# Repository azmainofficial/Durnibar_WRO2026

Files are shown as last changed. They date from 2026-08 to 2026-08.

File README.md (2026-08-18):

<div align="center">
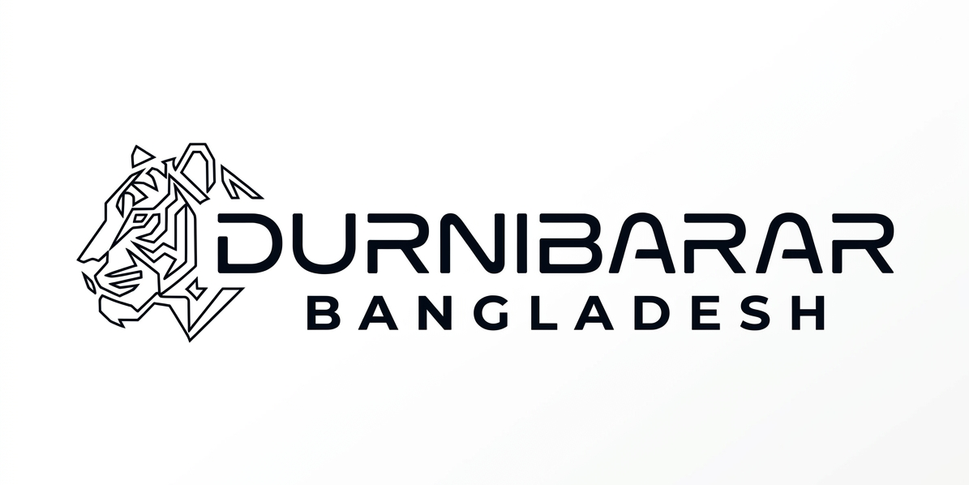
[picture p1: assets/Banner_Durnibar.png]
Team Durnibar Banner
  
  <h1>🏎️ Team Durnibar — WRO 2026 Future Engineers</h1>
  <p><strong>Official Repository & Technical Documentation for World Robot Olympiad 2026 (Self-Driving Cars)</strong></p>
  <p>Representing <strong>Bangladesh 🇧🇩</strong></p>

  
  
  
  
  
</div>

---

## 📌 Table of Contents

- [1. Team Introduction](#1-team-introduction)
- [2. Mission & WRO 2026 Rules Overview](#2-mission--wro-2026-rules-overview)
- [3. Vehicle System Architecture](#3-vehicle-system-architecture)
- [4. Repository Folder Hierarchy](#4-repository-folder-hierarchy)
- [5. Mechanical & Kinematic Design](#5-mechanical--kinematic-design)
- [6. Power & Sensor Management (Wiring & Pinout)](#6-power--sensor-management-wiring--pinout)
- [7. Software Modules, Telemetry & Algorithm Strategy](#7-software-modules-telemetry--algorithm-strategy)
- [8. Hardware Components & Bill of Materials](#8-hardware-components--bill-of-materials)
- [9. Build, Calibration & Run Instructions](#9-build-calibration--run-instructions)
- [10. Autonomous Demonstration Videos](#10-autonomous-demonstration-videos)
- [11. Judging Criteria & Documentation Index](#11-judging-criteria--documentation-index)

---

## 1. Team Introduction

**Team Durnibar** is a collegiate robotics team from Bangladesh competing in the **Future Engineers** category at the **World Robot Olympiad (WRO) 2026**.

<table align="center">
  <tr>
    <td align="center" width="33%">
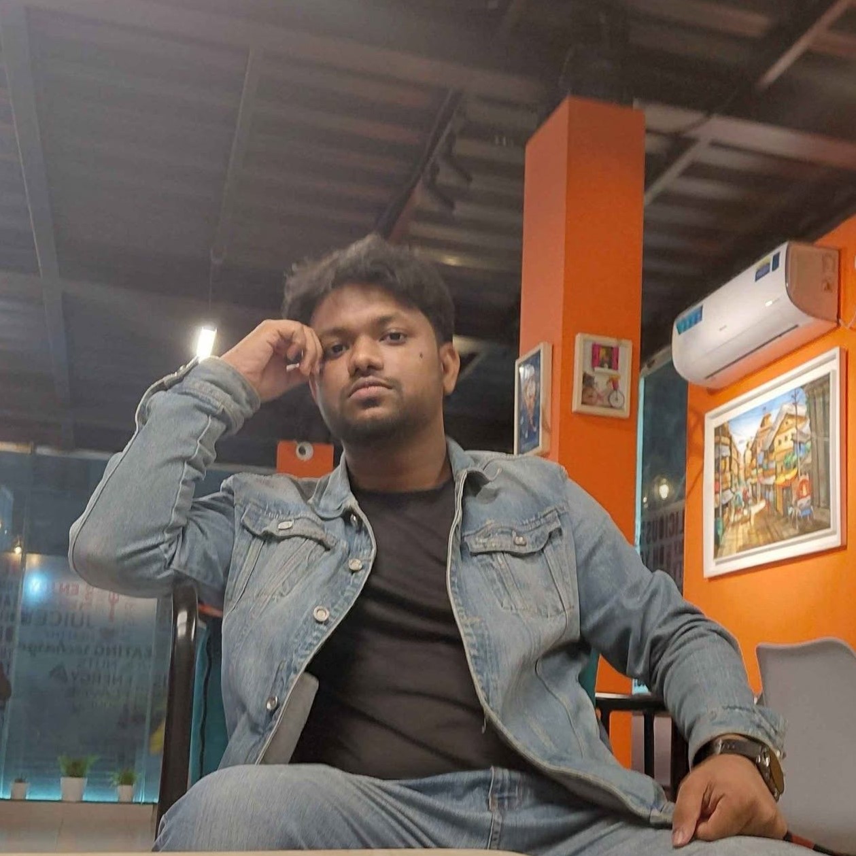
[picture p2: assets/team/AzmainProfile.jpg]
      <br><br>
      <strong>Azmain Shak Rubayed</strong><br>
      <sub>Team Lead / CAD & Vision Systems</sub><br>
      <sub>Fusion 360, ROS 2, OpenCV, Python</sub><br>
      <a href="mailto:rubayed_41220200226@nub.ac.bd">✉️ Email</a>
    </td>
    <td align="center" width="33%">
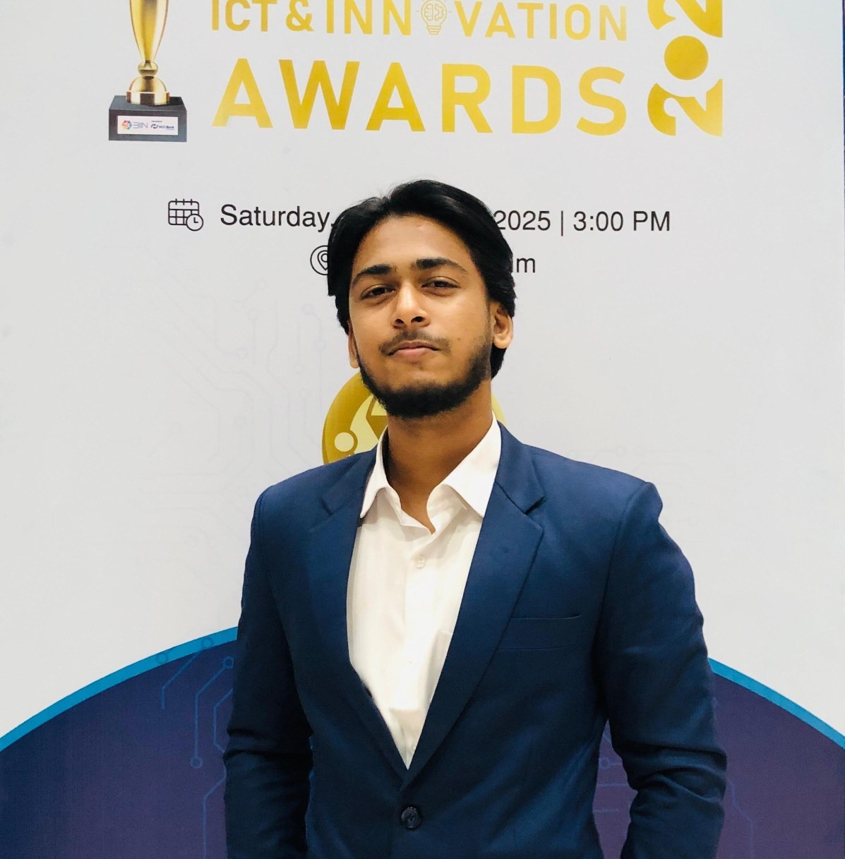
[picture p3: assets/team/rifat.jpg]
      <br><br>
      <strong>Rifat Ahmmed</strong><br>
      <sub>Embedded Software & Control</sub><br>
      <sub>Independent University Bangladesh</sub><br>
      <a href="mailto:ra7260352@email.com">✉️ Email</a>
    </td>
    <td align="center" width="33%">
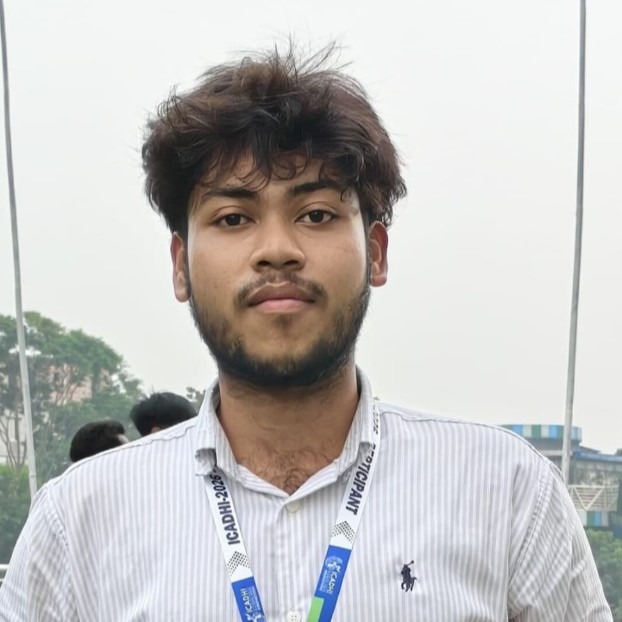
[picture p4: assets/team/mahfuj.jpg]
      <br><br>
      <strong>Mahfuj Rohoman</strong><br>
      <sub>Electronics & Hardware Integration</sub><br>
      <sub>Independent University, Bangladesh</sub><br>
      <a href="mailto:member3@email.com">✉️ Email</a>
    </td>
  </tr>
</table>

---

## 2. Mission & WRO 2026 Rules Overview

The **WRO 2026 Future Engineers Self-Driving Cars** category challenges teams to engineer an autonomous 4-wheeled robotic vehicle capable of high-speed navigation, obstacle traffic sign obedience, and autonomous parallel parking on a randomly configured racetrack.

b3b44990-8981-4bee-be3b-6bd4b68e230d

### WRO 2026 Competition Challenges

#### 1. Open Challenge
- Complete **3 autonomous laps** on a track with randomly configured inner walls.
- Navigate corridors with variable widths of **600 mm or 1000 mm**.
- After completing the third lap, the robot must **autonomously stop completely within the designated finish area (with custom 15cm forward wall-avoidance adjustment)**.

#### 2. Obstacle Challenge
- Complete **3 autonomous laps** while correctly following traffic signs:
  - **Red Pillar → Keep Right**
  - **Green Pillar → Keep Left**
- Perform **autonomous parallel parking** inside a designated **20 cm-wide parking area**.



### Key Technical Rule Compliance Checklist
- **Rule 11.1 & 11.2**: Max dimensions $300 \text{ mm (L)} \times 200 \text{ mm (W)} \times 300 \text{ mm (H)}$, max weight $1.5 \text{ kg}$.
- **Rule 11.3 & 11.13**: 4-wheeled vehicle with **one single driving axle** connected via gearbox and **one steering actuator**. Differential drive (skid steering) and independent side motors are strictly prohibited.
- **Rule 9.10 & 9.11**: Vehicle power activated by **exactly one main switch**; program execution triggered by **exactly one start button**.
- **Rule 11.10**: Strictly 100% autonomous operation — no RF, Bluetooth, Wi-Fi, or remote communication during competition attempts.

---

## 3. Vehicle System Architecture

**Durnibar 2.0 ("Sulg")** uses a decoupled two-tier architecture balancing ROS 2 high-level navigation with real-time microcontroller actuator response:

```
┌─────────────────────────────────────────────────────────────────────────┐
│              HIGH-LEVEL COMPUTATION — RASPBERRY PI 5 (8GB)              │
│   • ROS 2 Humble/Jazzy Operating Framework                              │
│   • Slamtec RPLIDAR C1 (360° DTOF LaserScan Navigation & Wall Tracking) │
│   • Fifine K420 2K Webcam (108° FOV OpenCV Traffic Sign Color Detection)│
│   • High-Level ROS 2 Finite State Machine (FSM) Decision Node           │
└────────────────────────────────────┬────────────────────────────────────┘
                                     │ High-Speed UART (115200 Baud)
┌────────────────────────────────────▼────────────────────────────────────┐
│                    LOW-LEVEL CONTROLLER — ESP32 MCU                     │
│   • TB6612FNG H-Bridge Motor Driver (PWMA=13, AIN1=12, AIN2=14, STBY=27)  │
│   • Quadrature Wheel Encoder ISR (A=34, B=35) & 1D Kalman Speed Filter  │
│   • MPU6050 6-DOF IMU + QMC5883L Compass + SSD1306 OLED Display (I2C)   │
│   • Closed-Loop Steering Servo PWM (GPIO 25) & Status LEDs / Buzzer     │
└─────────────────────────────────────────────────────────────────────────┘
```

---

## 4. Repository Folder Hierarchy

```
Sulg/ (Workspace Root)
├── Sulg.ino                 # ESP32 Main Sketch Setup & Loop
├── config.h                 # ESP32 pin definitions & parameters
├── globals.h                # Global state external declarations
├── imu.cpp / imu.h          # MPU6050 & QMC5883L IMU sensor fusion
├── motor.cpp / motor.h      # TB6612 Motor driver control functions
├── encoder.cpp / encoder.h  # Hardware quadrature encoder ticks
├── odometry.cpp / .h        # Wheel-odometry displacement tracking
├── pi_comm.cpp / pi_comm.h  # Unified Raspberry Pi Serial parser & 20Hz Telemetry
├── peripherals.cpp / .h     # LEDs, Non-blocking Buzzer & debounced buttons
├── hardware_test.cpp / .h   # Diagnostic Board Self-Tests
├── calibration.cpp / .h     # Gyro, Accel, and Magnetometer EEPROM calibration
├── oled_display.cpp / .h    # SSD1306 OLED screen rendering
│
├── LICENSE                  # MIT Open Source License
├── docs/                    # Detailed Technical Documentation (Appendix C Judging Criteria)
│   ├── README.md            # Documentation Index
│   ├── 01_mobility_and_mechanics.md     # Criterion 1: Ackermann steering, gear ratio, torque calculations
│   ├── 02_power_and_sensors.md          # Criterion 2: Power budget, wiring map, ToF & IMU placement
│   ├── 03_software_and_obstacle.md      # Criterion 3: ROS 2 nodes, FSM state machine, CV, parking logic
│   ├── 04_systems_thinking_decisions.md # Criterion 4: Trade-off analysis, constraints, FMECA matrix
│   └── 05_reproducibility_guide.md      # Criterion 5: Complete BOM, step-by-step build & flash guide
│
├── journal/                 # Engineering Journal & Testing Records
│   ├── README.md            # Journal overview
│   └── testing_logs.md      # Practice lap metrics, PID tuning, parking success rates
│
├── models/                  # 3D CAD Designs & Print Files
│   ├── README.md            # Model directory index
│   ├── cad_source/          # Fusion 360 source models (Durnibar 2.0.f3z, Gear Box v2.0.f3d)
│   └── 3d_print_files/      # Printable STL / STEP files
│
├── schematics/              # Electrical Layout & Pinouts
│   ├── README.md            # ESP32 pinout table & electrical specs
│   └── wiring_diagram.png   # System power & signal wiring map
│
├── assets/                  # Images & Media
│   ├── Banner_Durnibar.png  # Team banner
│   ├── team/                # Member profile photos
│   └── vehicle/             # Vehicle photos (Front, Back, Left, Right, Top, Bottom)
│
├── videos/                  # Autonomous Driving Demonstrations
│   └── README.md            # YouTube links for Open & Obstacle Challenge (>30s runs)
│
├── ros2_ws/                 # ROS 2 Active/Staging Workspace
│   └── src/
│       ├── sulg_robot/      # Robot configurations, launch files, URDF & scripts
│       └── sllidar_ros2/    # RPLiDAR ROS 2 Driver Node
│
├── pi_code/                 # Raspberry Pi 5 Active/Staging Folder
│   ├── wro_pi_system.py     # Multithreaded Vision, RPLiDAR C1 & Web Control Server
│   ├── optimal_planner.py   # Vectorized Ackermann Optimal Trajectory & Path Optimizer (Sub-3ms)
│   ├── disparity_extender.py# Disparity Extender safety bubble & gap finder
│   ├── yolo_detector.py     # Fast HSV color segmentation & Camera undistortion
│   ├── hsv_config.json      # Color thresholds, planner weights & hardware parameters
│   ├── deploy_to_pi.py      # SSH/SCP automatic sync script
│   └── templates/index.html # Zero-lag HTML5 dashboard, Vector Radar & Trajectory Spline Ribbon
│
├── round1_open_challenge/   # Isolated Challenge 1 (Open Challenge) reactive LiDAR codebase
├── round1_open_challenge_odometry/ # Isolated Challenge 1 (Open Challenge) odometry waypoint codebase
├── round1_open_challenge_discrete/ # Isolated Challenge 1 (Open Challenge) discrete cornering state machine
└── round2_obstacle_challenge/ # Isolated Challenge 2 (Obstacle Challenge) codebase
```

---

## 5. Mechanical & Kinematic Design

Per **Criterion 1 (Mobility & Mechanical Design)**, Durnibar 2.0 uses **Ackermann Steering Kinematics** combined with a custom **24:1 two-stage spur gearbox transmission** driven by a single rear axle:

### Ackermann Steering Equation
$$\cot(\delta_o) - \cot(\delta_i) = \frac{W}{L}$$

Where $W = 145 \text{ mm}$ (track width) and $L = 175 \text{ mm}$ (wheelbase). This ensures all four wheels rotate around a single Instantaneous Center of Rotation (ICR), preventing tire slippage on narrow turns.

For complete mechanical equations, torque calculations, and CAD iteration history, see **[docs/01_mobility_and_mechanics.md](./docs/01_mobility_and_mechanics.md)**.


---

## 6. Power & Sensor Management (Wiring & Pinout)

Per **Criterion 2 (Power & Sensor Architecture)**, power is delivered by a **3S 11.1V 2200mAh LiPo battery** through isolated power rails:
- **High-Current Rail ($11.1\text{ V}$)**: Powers the rear brushless drive motor ESC directly.
- **Regulated Power Rail ($5.0\text{ V} / 5\text{ A}$)**: High-efficiency buck regulator supplying the Raspberry Pi 5 (8GB), ESP32 MCU, Fifine K420 webcam, ToF sensors, and IMU.

### ESP32 Pin Connections
| Component | ESP32 Pin | Description |
|---|---|---|
| **Steer Servo** | GPIO 25 | PWM steer output (SG90) |
| **TB6612 PWMA** | GPIO 13 | Motor speed PWM |
| **TB6612 AIN1** | GPIO 12 | Motor direction 1 |
| **TB6612 AIN2** | GPIO 14 | Motor direction 2 |
| **TB6612 Standby**| GPIO 27 | Active-high driver enable |
| **Encoder Channel A** | GPIO 34 | Quadrature pulse A |
| **Encoder Channel B** | GPIO 35 | Quadrature pulse B |
| **I2C SDA** | GPIO 21 | SSD1306 OLED, MPU6050 & QMC5883L |
| **I2C SCL** | GPIO 22 | I2C clock line |
| **Buzzer** | GPIO 26 | Piezo buzzer output |
| **Button 1** | GPIO 32 | Start Open Challenge (Active-LOW) |
| **Button 2** | GPIO 33 | Start Obstacle Challenge (Active-LOW) |
| **BOOT Button** | GPIO 0 | Trigger IMU Calibration (Active-LOW) |
| **LED Green** | GPIO 17 | Status indication |
| **LED Yellow** | GPIO 16 | Status indication |
| **LED Red** | GPIO 4 | Error / status indication |

### Raspberry Pi 5 Interfaces
* **USB Port 1**: Silicon Labs CP2102 USB-to-UART Bridge → **RPLiDAR C1** (460800 baud).
* **USB Port 2**: CH340 / CP2102 Serial Connection → **ESP32 Controller** (115200 baud).
* **USB Port 3**: **Fifine K420 Wide-Angle Camera** (640x368 YUYV Video Stream).

### System Power Budget Table

| Component Category | Devices | Total Nominal Power | Peak Current |
| :--- | :--- | :---: | :---: |
| **Compute & Vision** | Raspberry Pi 5 (8GB) + Fifine K420 Webcam | $10.50 \text{ W}$ | $4.00 \text{ A}$ |
| **Sensing & Logic** | ESP32 MCU + ToF + IMU | $0.83 \text{ W}$ | $0.51 \text{ A}$ |
| **Actuators & Motors** | Steering Servo + ESC Drive Motor | $18.45 \text{ W}$ | $7.30 \text{ A}$ |
| **Total System Load** | — | **$29.78 \text{ W}$** | **$11.81 \text{ A}$** |

For complete electrical schematics, pinouts, and sensor placement geometry, see **[docs/02_power_and_sensors.md](./docs/02_power_and_sensors.md)**.

---

## 7. Software Modules, Telemetry & Algorithm Strategy

Per **Criterion 3 (Software Architecture & Obstacle Strategy)**, software modules are decoupled into clean ROS 2 packages and Python nodes:

1. **Vision Module (`pi_code/yolo_detector.py`)**: Uses HSV color segmentation and adaptive thresholding on 1080p frames from the Fifine K420 webcam ($108^\circ$ FOV) to detect traffic sign pillars (Red = Pass Right, Green = Pass Left).
2. **Navigation Module (`pi_code/optimal_planner.py`)**: Computes PID steering adjustments and vectorized trajectory options to keep the vehicle centered in the track corridor.
3. **Serial Telemetry Protocol**:
The Raspberry Pi and ESP32 communicate at **115200 baud** over USB serial.
   - **ESP32 to Pi (ODOM packet @ 20 Hz)**:
     ```
     ODOM,X_mm,Y_mm,Yaw_deg,Dist_mm,Speed_mms,SensorsOK,Btn1,Btn2\n
     ```
   - **Pi to ESP32 (Control commands)**:
     * **Drive Command**: `D <speed> <steer>` (e.g. `D 130 110\n`)
       * `speed`: `-255` (full reverse) to `255` (full forward).
       * `steer`: `50` (full right) to `170` (full left). `110` is center.
     * **Stop Command**: `S\n` (sets motor to 0, centers wheels).
     * **Reset Command**: `R\n` (resets odometry coordinates and IMU reference to zero).

For complete FSM diagrams, vision pseudocode, and PID parameter tuning, see **[docs/03_software_and_obstacle.md](./docs/03_software_and_obstacle.md)**.

---

## 8. Hardware Components & Bill of Materials

Per **Criterion 5 (Reproducibility)**, below is the core hardware inventory:

| Component | Function / Role | Model / Part | Approx. Price |
| :--- | :--- | :--- | :---: |
| **Main SBC** | High-level vision & FSM | Raspberry Pi 5 (8GB RAM) | $80.00 |
| **Microcontroller** | Low-level PWM & sensor reading | ESP32 NodeMCU | $6.00 |
| **Camera** | Color traffic sign recognition | Fifine K420 2K Webcam ($108^\circ$ FOV) | $28.00 |
| **Distance Array** | Wall distance measurement | RPLiDAR C1 / ToF Sensors | $90.00 |
| **IMU** | Heading & orientation tracking | MPU6050 & QMC5883L | $8.00 |
| **Steering Servo** | Front wheel Ackermann control | Metal Gear Digital Servo | $12.00 |
| **Drive Motor** | Propulsion via 24:1 transmission | Brushless DC Motor + ESC / TB6612 | $22.00 |
| **Power Source** | Main vehicle battery | 3S 11.1V 2200mAh LiPo | $16.00 |

For full assembly guide and parts links, see **[docs/05_reproducibility_guide.md](./docs/05_reproducibility_guide.md)**.

---

## 9. Build, Calibration & Run Instructions

### 1. ESP32 Firmware & Calibration
* Rotate the bot slowly in a figure-8 motion on all axes during calibration. Offsets are automatically saved to EEPROM.
* Upload firmware to ESP32:
  ```bash
  # Flash ESP32 firmware via PlatformIO
  cd src/firmware
  pio run --target upload --upload-port /dev/ttyUSB0
  ```

### 2. Launching Raspberry Pi Control Server
Deploy the desired challenge codebase (Open Challenge or Obstacle Challenge) to the Pi, which uploads the files to the active staging directory (`~/pi_code`) on the Pi, and run the server:

**For Challenge 1 (Open Challenge):**
* **Option A: Reactive LiDAR Navigation (Default)**
  ```bash
  # Push reactive LiDAR code to Pi (deploys to ~/pi_code on Pi)
  python round1_open_challenge/deploy_to_pi.py
  
  # Run on Pi
  python3 pi_code/wro_pi_system.py
  ```
  
* **Option B: Closed-Loop Odometry Waypoint Navigation**
  ```bash
  # Push odometry waypoint code to Pi (deploys to ~/pi_code on Pi)
  python round1_open_challenge_odometry/deploy_to_pi.py
  
  # Run on Pi
  python3 pi_code/wro_pi_system.py
  ```

* **Option C: Discrete Cornering State Machine (Smooth Straight Lines)**
  ```bash
  # Push discrete state machine code to Pi (deploys to ~/pi_code on Pi)
  python round1_open_challenge_discrete/deploy_to_pi.py
  
  # Run on Pi
  python3 pi_code/wro_pi_system.py
  ```

**For Challenge 2 (Obstacle Challenge):**
```bash
# Push Challenge 2 code to Pi (deploys to ~/pi_code on Pi)
python round2_obstacle_challenge/deploy_to_pi.py

# Run on Pi
python3 pi_code/wro_pi_system.py
```
* Access the **Web Dashboard** at `http://192.168.1.101:5000` to adjust HSV color masks, set target speeds, calibrate cameras, and view live 2D lidar scans.

---

## 10. Autonomous Demonstration Videos

Per **Rule Section 7**, public YouTube video links demonstrating autonomous vehicle operation (>30 seconds per attempt) are available below:

- 📺 **[Open Challenge Autonomous Run](https://youtube.com/shorts/VsTFvdk8Iqs?si=F9PB8GRpVL1VrcOU)** — Complete 3-lap run with autonomous finish section stop.
- 📺 **[Obstacle Challenge Autonomous Run](https://youtu.be/H7GwOodIgsA)** — Complete 3-lap run with traffic sign obedience and parallel parking.

See **[videos/README.md](./videos/README.md)** for detailed video logs.

---

## 11. Judging Criteria & Documentation Index

Our technical documentation directly maps to the **WRO 2026 Appendix C Scoring Rubric (30 Points Total)**:

- 📗 **[Criterion 1: Mobility & Mechanical Design (6 pts)](./docs/01_mobility_and_mechanics.md)**
- 📘 **[Criterion 2: Power & Sensor Architecture (6 pts)](./docs/02_power_and_sensors.md)**
- 📙 **[Criterion 3: Software Architecture & Obstacle Strategy (6 pts)](./docs/03_software_and_obstacle.md)**
- 📕 **[Criterion 4: Systems Thinking & Engineering Decisions (6 pts)](./docs/04_systems_thinking_decisions.md)**
- 📓 **[Criterion 5: Reproducibility & GitHub Quality (6 pts)](./docs/05_reproducibility_guide.md)**
- 📑 **[Engineering Journal & Practice Logs](./journal/testing_logs.md)**

---

<div align="center">
  <sub>Developed with ❤️ by <strong>Team Durnibar</strong> for <strong>WRO 2026 Future Engineers</strong></sub>
</div>

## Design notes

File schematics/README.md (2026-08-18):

# ESP32 Pinout Mapping & Schematics Overview

> **WRO 2026 Future Engineers — Team Durnibar**

This document specifies the exact GPIO pin mapping for the **ESP32 NodeMCU** controller on **Durnibar 2.0**.

## 📌 Circuit Schematic Diagram

Schematic_WROBD_2026_2026-08-11

---

## 📌 Complete ESP32 Hardware Pin Diagram

| Device / Function | ESP32 GPIO | Signal Type | Notes & Operational Rationale |
| :--- | :---: | :---: | :--- |
| **TB6612 PWMA** | `GPIO 25` | PWM Output | Motor speed control ($0 - 255$ PWM) |
| **TB6612 AIN1** | `GPIO 26` | Digital Output | Motor direction bit 1 |
| **TB6612 AIN2** | `GPIO 27` | Digital Output | Motor direction bit 2 |
| **TB6612 STBY** | `GPIO 23` | Digital Output | H-Bridge Standby / Enable pin (Driven HIGH) |
| **Encoder Phase A** | `GPIO 34` | Input Only | Quadrature encoder interrupt pin for odometry |
| **Encoder Phase B** | `GPIO 35` | Input Only | Quadrature encoder direction reference |
| **Steering Servo** | `GPIO 18` | PWM Output | Ackermann steering servo pulse ($50\text{ Hz}$) |
| **Status Buzzer** | `GPIO 19` | PWM / Tone | Audio tone feedback & system warnings |
| **LED 1 (Green)** | `GPIO 16` | Digital Output | Status LED: System Active / Autonomous Run |
| **LED 2 (Yellow)**| `GPIO 17` | Digital Output | Status LED: Booting / Warning / Calibration |
| **LED 3 (Red)** | `GPIO 5`  | Digital Output | Status LED: Standby / Stop State |
| **Button 1** | `GPIO 13` | Input Pull-Up | **WRO 2026 Rule 9.11 Main Start Button** |
| **Button 2** | `GPIO 12` | Input Pull-Up | Calibration & mode toggle push button |
| **Button 3** | `GPIO 14` | Input Pull-Up | Hardware reset / Emergency stop button |
| **OLED SDA** | `GPIO 21` | Shared I2C | SSD1306 OLED display data ($0\times3\text{C}$) |
| **OLED SCL** | `GPIO 22` | Shared I2C | SSD1306 OLED display clock ($400\text{ kHz}$) |
| **MPU6050 SDA** | `GPIO 21` | Shared I2C | MPU6050 6-DOF IMU data ($0\times68$) |
| **MPU6050 SCL** | `GPIO 22` | Shared I2C | MPU6050 6-DOF IMU clock ($400\text{ kHz}$) |
| **QMC5883L SDA**  | `GPIO 21` | Shared I2C | QMC5883L Magnetometer data ($0\times0\text{D}$) |
| **QMC5883L SCL**  | `GPIO 22` | Shared I2C | QMC5883L Magnetometer clock ($400\text{ kHz}$) |

---

## ⚡ Electrical Interface Rationale
1. **TB6612FNG H-Bridge Driver**: Driving `STBY` (GPIO 23) HIGH enables the motor outputs; setting `AIN1/AIN2` controls forward/reverse direction while `PWMA` (GPIO 25) regulates speed.
2. **Dedicated Input-Only Pins**: `GPIO 34` and `GPIO 35` are used exclusively for encoder inputs, ensuring zero conflict with output peripherals.
3. **Shared I2C Bus**: OLED display, MPU6050 IMU, and QMC5883L compass communicate over a single high-speed I2C bus (`GPIO 21` / `GPIO 22`) running at $400\text{ kHz}$.

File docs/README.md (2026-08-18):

# Team Durnibar — Technical Documentation Directory

Welcome to the technical documentation repository for **Team Durnibar** participating in the **WRO 2026 Future Engineers (Self-Driving Cars)** category. 

This folder contains comprehensive engineering documentation structured directly around the **WRO 2026 Official Rules and Appendix C Judging Criteria**.

---

## 📑 Documentation Structure

Our documentation is split into five core technical reports corresponding to the judging rubrics:

| File | Judging Criterion | Focus & Key Contents |
| :--- | :--- | :--- |
| **[01_mobility_and_mechanics.md](./01_mobility_and_mechanics.md)** | **Criterion 1: Mobility & Mechanical Design** | Ackermann steering geometry, single rear-axle differential drive, gear ratio & torque calculations, CAD iterations, chassis rigidity. |
| **[02_power_and_sensors.md](./02_power_and_sensors.md)** | **Criterion 2: Power & Sensor Architecture** | Power budget & distribution, LiPo battery regulation, ToF/LiDAR/Camera placement geometry, pinout map, sensor calibration. |
| **[03_software_and_obstacle.md](./03_software_and_obstacle.md)** | **Criterion 3: Software Architecture & Obstacle Strategy** | Modular software pipeline, Finite State Machine (FSM), OpenCV pillar recognition (Red=Right, Green=Left), PID steering control, Parallel Parking algorithm. |
| **[04_systems_thinking_decisions.md](./04_systems_thinking_decisions.md)** | **Criterion 4: Systems Thinking & Engineering Decisions** | Architectural tradeoffs, physical & computational constraints, failure mode matrix & mitigation, version history (v1.0 -> v2.0). |
| **[05_reproducibility_guide.md](./05_reproducibility_guide.md)** | **Criterion 5: Reproducibility & Build Guide** | Complete Bill of Materials (BOM), step-by-step assembly guide, software compilation & firmware flashing instructions. |

---

## 🎯 Scoring & Evaluation Quick Reference

According to **Appendix C of the WRO 2026 General Rules**, the documentation is evaluated out of **30 points** across these 5 criteria:

- **6 Points per Criterion**: Requires advanced engineering, quantitative trade-off analysis, explicit formulas/calculations, failure handling, testing metrics, and complete reproducibility.
- **Rules Compliance Checklist**:
  - Maximum dimensions: $300 \text{ mm (L)} \times 200 \text{ mm (W)} \times 300 \text{ mm (H)}$.
  - Maximum weight: $1.5 \text{ kg}$.
  - Single drive axle with physical differential / connected wheels (Rule 11.3 & 11.13). Independent motors per side / differential drive bases are strictly prohibited.
  - Exactly one main power switch and one start button (Rule 9.10 & 9.11).

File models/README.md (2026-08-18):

# 3D CAD Models & Manufacturing Files

> **WRO 2026 Future Engineers — Team Durnibar**

This folder contains all 3D CAD design files, assemblies, and manufacturing models for **Durnibar 2.0**.

---

## 📂 Subdirectories

- **[`cad_source/`](./cad_source/)**: Fusion 360 source files (`Durnibar 2.0.f3z` robot model, `Gear Box v2.0.f3d` 2-stage transmission).
- **[`3d_print_files/`](./3d_print_files/)**: Printable STL / STEP files for chassis components, sensor brackets, gear sets, and mounts.

---

## 🖨 Recommended 3D Printing Settings

- **Material**: PETG or ABS (for impact resistance during wall contact)
- **Layer Height**: 0.20 mm
- **Infill**: 40% Gyroid infill for high strength-to-weight ratio
- **Perimeters**: 4 walls / 4 top & bottom layers

---

## 🔍 Viewing the 3D CAD Files

To view and interact with the 3D design models (such as `.f3d`, `.f3z`, and `.stl` files) in this repository:

### Method 1: Visual Studio Code (Recommended)
This repository includes a VS Code configuration that recommends CAD/3D viewer extensions:
1. Open this repository folder in **VS Code**.
2. You will be prompted to install the recommended extensions. Click **Install**.
3. Alternatively, open the Extensions marketplace (`Ctrl+Shift+X`) and install:
   * **CAD Viewer** (`thingraph.cad-viewer`)
   * **STL Viewer** (`mike-lischke.vscode-stl-viewer`)
4. Simply double-click any `.stl`, `.step`, or `.gltf` file to open and orbit the model interactively.

### Method 2: Autodesk Viewer (Free & Web-Based)
Since `.f3d` and `.f3z` are proprietary Autodesk Fusion 360 files:
1. Open the free online [Autodesk Viewer](https://viewer.autodesk.com/).
2. Upload the file (e.g., [`Durnibar 2.0.f3z`](./cad_source/Durnibar%202.0.f3z) or [`Gear Box v2.0.f3d`](./cad_source/Gear%20Box%20v2.0.f3d)).
3. This allows you to explore assemblies, isolate parts, measure dimensions, and view the full 3D assembly structure in your browser.

### Method 3: GitHub 3D Viewer (For STL models)
When browsing this repository on GitHub.com, simply click on any `.stl` model file. GitHub has a built-in WebGL interactive viewer that allows you to rotate, pan, and zoom the model directly in your browser.

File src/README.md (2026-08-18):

# ROS 2 & ESP32 Source Code Directory

> **WRO 2026 Future Engineers — Team Durnibar**

This folder contains the complete, modular ROS 2 node architecture and low-level ESP32 C++ firmware powering **Durnibar 2.0**.

---

## 📁 Source Package Architecture

```
src/
├── durnibar_bringup/    # ROS 2 bringup launch files (RPLIDAR C1 + Fifine K420 camera + FSM)
├── durnibar_nav/        # RPLIDAR C1 360° LaserScan navigation & PID steering node
├── durnibar_vision/     # Fifine K420 108° camera OpenCV color pillar detection node
├── durnibar_fsm/        # High-level WRO 2026 Finite State Machine node
└── firmware/            # ESP32 C++ firmware & Arduino IDE / PlatformIO code
```

---

## 🚀 Building the ROS 2 Packages (Raspberry Pi 5)

```bash
# 1. Source ROS 2 Humble environment
source /opt/ros/humble/setup.bash

# 2. Build workspace using colcon
cd ~/ros2_ws
colcon build --symlink-install

# 3. Source installation
source install/setup.bash

# 4. Launch full robot system (RPLIDAR C1 + Camera + Navigation + FSM)
ros2 launch durnibar_bringup robot_launch.py
```

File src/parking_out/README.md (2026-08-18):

# Parking Out Subsystem

This folder is dedicated to the **Parking Out** autonomous navigation task (navigating out of a parallel/perpendicular parking slot to enter the main track).

## Goals & Objectives
* Initialize vehicle start pose inside the parking lot.
* Detect slot bounds and track openings.
* Execute a reverse/forward steering sequence to exit the parking lane and enter the challenge ring.

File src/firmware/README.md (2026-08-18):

# ESP32 Firmware Guide — Team Durnibar WRO 2026

This directory contains the low-level C++ firmware for the **ESP32 NodeMCU** microcontroller on **Durnibar 2.0**.

---

## 📌 Features & Responsibilities

1. **Ackermann Steering Servo Control**: Servo PWM on **GPIO 18** ($50\text{ Hz}$), with safety bounds ($62^\circ$ to $118^\circ$).
2. **Brushless ESC Motor Drive Control**: ESC PWM on **GPIO 19** ($1100\mu\text{s}$ reverse to $1900\mu\text{s}$ forward, $1500\mu\text{s}$ neutral).
3. **4x Time-of-Flight (ToF) Distance Array**: Reads 4x VL53L1X distance sensors over I2C using XSHUT multiplexing on **GPIO 25, 26, 27, 14**.
4. **9-DOF IMU Orientation Tracking**: Reads BNO055 orientation sensor over I2C (**GPIO 21 SDA, GPIO 22 SCL**).
5. **WRO 2026 Rule 9.11 Start Button**: Dedicated push button on **GPIO 4** with internal pull-up and hardware debouncing.
6. **High-Speed Serial Bridge to Raspberry Pi 5**: Telemetry streaming at $50\text{ Hz}$ and command parsing over Serial2 UART (**GPIO 16 RX2, GPIO 17 TX2**) at 115200 baud.

---

## 🛠 How to Build & Flash with Arduino IDE (Primary Method)

### 1. Arduino IDE Setup
1. Open **Arduino IDE** (v2.0+ recommended).
2. Go to **File ➔ Preferences** and add the ESP32 Board Manager URL to *Additional Boards Manager URLs*:
   `https://raw.githubusercontent.com/espressif/arduino-esp32/gh-pages/package_esp32_index.json`
3. Go to **Tools ➔ Board ➔ Boards Manager...**, search for `esp32` by Espressif Systems, and click **Install**.

### 2. Required Libraries Installation
Go to **Tools ➔ Manage Libraries...** (or `Ctrl+Shift+I`) and install:
- **`ESP32Servo`** by Kevin Harrington
- **`Adafruit MPU6050`** by Adafruit
- **`Adafruit SSD1306`** by Adafruit
- **`Adafruit GFX Library`** by Adafruit

### 3. Open & Upload Sketch
1. Open the sketch located at:
   `src/firmware/esp32_firmware/esp32_firmware.ino`
2. Connect your ESP32 board via USB.
3. Select Board: **Tools ➔ Board ➔ ESP32 Arduino ➔ ESP32 Dev Module**.
4. Select Port: **Tools ➔ Port ➔ COMx** (Windows) or `/dev/ttyUSB0` (Linux/Mac).
5. Click **Upload** (Arrow icon).

---

## 🛠 PlatformIO Setup (Alternative Method)

```bash
cd src/firmware
pio run --target upload --upload-port /dev/ttyUSB0
```

---

## 📡 Serial Telemetry & Command Protocol

### Telemetry Packet (ESP32 ➔ RPi 5 @ 50Hz)
```
$TEL,<DistFL_mm>,<DistFR_mm>,<DistSL_mm>,<DistSR_mm>,<YawAngle_deg>,<StartBtnState>#
Example: $TEL,450,448,180,185,90.5,1#
```

### Command Packet (RPi 5 ➔ ESP32)
```
$CMD,<SteeringAngle_deg>,<MotorThrottle_us>#
Example: $CMD,90,1580#
```

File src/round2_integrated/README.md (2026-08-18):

# Raspberry Pi 5 – Challenge 1 (Open Challenge) Odometry Waypoint Subsystem

This folder contains the isolated Raspberry Pi 5 scripts configured to perform **closed-loop Odometry Waypoint Navigation** for **Challenge 1 (Open Challenge)** using $(X, Y)$ coordinate tracking and IMU yaw from the ESP32.

---

## 🔌 Connection Details

| Field | Value |
|---|---|
| **Pi User** | `azmain` |
| **Pi IP** | `192.168.137.137` |
| **Remote Dir** | `~/pi_code/` |
| **SSH Password** | `123` |

---

## 📶 Network Modes — Works With OR Without WiFi

### Mode A — Connected to known WiFi / USB tethering
Dashboard at: **`http://192.168.137.137:5000`**

### Mode B — No network available (competition venue, field, etc.)
The Pi creates **its own WiFi hotspot** automatically:

| Field | Value |
|---|---|
| **Hotspot SSID** | `WRO-Robot` |
| **Password** | `wro12345` |
| **Dashboard URL** | `http://10.42.0.1:5000` |

Connect your phone or laptop to `WRO-Robot` and open the dashboard — no router needed.

> **One-time setup required.** Run `setup_hotspot.sh` once on the Pi (see below).

---

## 🚀 One-Time Setup on Pi (Run Once via SSH)

SSH into the Pi, then run these commands **once** to register the service and enable auto-start on every boot:

```bash
ssh azmain@192.168.137.137

# 1. Copy the service file to systemd
sudo cp ~/pi_code/wro_nav.service /etc/systemd/system/wro_nav.service

# 2. Reload systemd to pick up the new service
sudo systemctl daemon-reload

# 3. Enable the service to auto-start on every boot
sudo systemctl enable wro_nav.service

# 4. Set up the WiFi hotspot fallback (no-network mode)
bash ~/pi_code/setup_hotspot.sh

# 5. Start it immediately (no reboot needed)
sudo systemctl start wro_nav.service

# 6. Verify it is running
sudo systemctl status wro_nav.service
```

After this, every time you **power on** the Pi, the navigation system starts automatically within ~10 seconds.

---

## 🎮 Button Operation (After Boot)

The system starts in **IDLE** mode automatically. Buttons on the ESP32 control the challenge:

| Button | First Press | Press Again |
|---|---|---|
| **Button 1** | ▶ Start **Open Challenge** (3 laps) | ■ Stop / Go IDLE |
| **Button 2** | ▶ Start **Obstacle Challenge** (3 laps → Auto-Park) | ■ Stop / Go IDLE |

> After 3 laps in Open Challenge, the bot stops automatically in the designated area.
> After 3 laps in Obstacle Challenge, it automatically enters parallel parking mode.

---

## 📊 Live Web Dashboard

While the bot is running, open a browser on any device connected to the same network:

```
http://192.168.137.137:5000
```

The dashboard shows:
- **Live annotated camera feed** (16:9 640×360)
- **HSV binary mask preview**
- **RPLiDAR C1 radar canvas** with trajectory overlays
- **Real-time telemetry**: FPS, yaw, speed, wall distances, lap count
- **Planner controls**: Adjust weights, speed, FOV live

---

## 🔧 Service Management Commands

```bash
# View live logs from the service
journalctl -u wro_nav -f

# Restart the service (e.g. after deploying new code)
sudo systemctl restart wro_nav.service

# Stop the service
sudo systemctl stop wro_nav.service

# Disable auto-start (if needed)
sudo systemctl disable wro_nav.service
```

---

## 📦 Deploying Code Updates from PC

Run this from your Windows PC to push all updated files to the Pi:

```bash
python pi_code/deploy_to_pi.py
```

After deploying, restart the service on the Pi:
```bash
ssh azmain@192.168.137.137 "sudo systemctl restart wro_nav.service"
```

---

## 🧪 Sensor Diagnostics

Before running a competition, verify all hardware is working:

```bash
ssh azmain@192.168.137.137 "cd ~/pi_code && python3 test_sensors.py"
```

Expected output:
```
- Camera (Fifine K420) : PASS [OK]
- RPLiDAR C1 Scanner   : PASS [OK]
```

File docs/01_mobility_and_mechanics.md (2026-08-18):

# Criterion 1: Mobility and Mechanical Design

> **WRO 2026 Future Engineers — Technical Report**  
> **Team Durnibar | Bangladesh**

---

## Table of Contents
1. [Quick Reference Specifications](#1-quick-reference-specifications)
2. [Regulatory Compliance](#2-regulatory-compliance)
3. [Steering System — Ackermann Mechanism](#3-steering-system--ackermann-mechanism)
4. [Drivetrain — Motor & Gear Reduction](#4-drivetrain--motor--gear-reduction)
5. [Chassis Architecture & Materials](#5-chassis-architecture--materials)
6. [Design Iteration History](#6-design-iteration-history)
7. [Power Distribution System](#7-power-distribution-system)
   - [7.1 Power Architecture](#71-power-architecture)
   - [7.2 Current Consumption Calculation](#72-current-consumption-calculation)
   - [7.3 Battery Runtime Estimation](#73-battery-runtime-estimation)
   - [7.4 ESP32 Microcontroller GPIO Pin Configuration](#74-esp32-microcontroller-gpio-pin-configuration)
8. [Electronic Components List](#8-electronic-components-list)

---

## 1. Quick Reference Specifications

| Parameter | Value |
|---|---|
| Overall dimensions | 300 mm (L) × 200 mm (W) × 300 mm (H) max |
| Mass | ≤ 1.5 kg |
| Drive configuration | Single driving axle (rear) |
| Steering mechanism | Ackermann steering, single actuator |
| Wheelbase ($L$) | 175 mm |
| Track width ($W$) | 145 mm |
| Wheel diameter ($D$) | 65 mm |
| Motor | High-torque Brushed DC, 8,500 RPM @ 11.1V |
| Gear reduction | 24:1 (2-stage: 1:4 → 1:6) |
| Target top speed | 1.2 m/s |
| Achieved output speed | 1.16 m/s |
| Chassis | Dual-deck — Carbon fiber/acrylic (lower) + PETG 3D print (upper) |

---

## 2. Regulatory Compliance

Per **Section 11 of the WRO 2026 Future Engineers General Rules**, the vehicle satisfies all dimensional and kinematic requirements:

| Rule | Requirement | Compliance |
|---|---|---|
| Dimensions | ≤ $300 \times 200 \times 300\text{ mm}$ ($L \times W \times H$) | ✅ Within limit |
| Mass | ≤ $1.5\text{ kg}$ | ✅ Within limit |
| Drive kinematics (11.3) | 4-wheeled, one driving axle (front/rear/4WD), one steering actuator | ✅ Rear-driven, single steering servo |
| Prohibited systems (11.4 & 11.5) | No differential/skid steering, omni wheels, ball casters, or independent-side-motor electronic differentials | ✅ None used |

---

## 3. Steering System — Ackermann Mechanism

To achieve smooth cornering without tire scrub on the narrow **600–1000 mm** track corridors, **Team Durnibar** implemented an **Ackermann steering mechanism**.

```
         ┌────────────────────────┐
         │       Front Axle       │
  Wheel  │   o─────────o          │  Wheel
 ┌─────┐ │  /           \         │ ┌─────┐
 │     │─┼─o   Steering   o───────┼─│     │
 └─────┘ │  \    Tie-Rod /        │ └─────┘
         │   └───o───o──┘         │
         │       │   │            │
         │    Servo Lever         │
         └────────────────────────┘
```

### Ackermann Geometry Calculations
For a wheelbase $L = 175\text{ mm}$ and track width $W = 145\text{ mm}$, the inner ($\delta_i$) and outer ($\delta_o$) wheel angles during a turn of radius $R$ satisfy the following equations:

$$\cot(\delta_o) - \cot(\delta_i) = \frac{W}{L}$$

$$\delta_o = \arctan\left(\frac{L}{\dfrac{L}{\tan(\delta_i)} + W}\right)$$

This layout keeps all four wheels tracing concentric circles around a common **Instantaneous Center of Rotation (ICR)**, eliminating sideways tire drag and power loss during high-speed cornering maneuvers.

---

## 4. Drivetrain — Motor & Gear Reduction

The drive system uses a single high-torque DC motor coupled to the rear axle through a custom **2-stage spur gear transmission**, designed in Fusion 360 ([`Gear Box v2.0.f3d`](file:///d:/Durnibar26/models/cad_source/Gear%20Box%20v2.0.f3d)).

### 4.1 Design Targets

| Quantity | Value |
|---|---|
| Motor rated speed | 8,500 RPM @ 11.1V |
| Target robot top speed | 1.2 m/s (matched to 30 FPS vision processing latency) |
| Wheel diameter $D$ | 65 mm → circumference $C = \pi D = 0.2042\text{ m}$ |

### 4.2 Gear Ratio Derivation

**Step 1 — Required wheel RPM** for target speed:
$$N_{wheel} = \frac{v}{C} \times 60 = \frac{1.2}{0.2042} \times 60 \approx 352.6 \text{ RPM}$$

**Step 2 — Required total reduction ratio:**
$$i_{total} = \frac{N_{motor}}{N_{wheel}} = \frac{8500}{352.6} \approx 24.1 : 1$$

**Selected ratio: 24:1** (1:4 first stage × 1:6 second stage), giving:
- **Output speed:** 1.16 m/s
- **Stall torque multiplier:** $24\times$ — provides ample torque for standing-start acceleration and precise parallel-parking maneuvers.

---

## 5. Chassis Architecture & Materials

The chassis ([`Durnibar 2.0.f3z`](file:///d:/Durnibar26/models/cad_source/Durnibar%202.0.f3z)) is built as a **dual-deck** structure to separate high-level compute from drive electronics:

| Deck | Material | Houses |
|---|---|---|
| **Lower deck** | 3 mm carbon fiber / acrylic sheet | Rear drive assembly, steering servo, LiPo battery, low-level power electronics |
| **Upper deck** | 3D-printed PETG | Raspberry Pi / SBC compute unit, camera mount, ToF sensors, IMU |

```
┌───────────────────────────────────────────────────────────────┐
│                          UPPER DECK                            │
│    [Camera Mount]      [Raspberry Pi / SBC]      [IMU]         │
├───────────────────────────────────────────────────────────────┤
│                          LOWER DECK                            │
│   [Steering Servo]    [LiPo Battery]       [Motor & Gearbox]   │
└───────────────────────────────────────────────────────────────┘
```

---

## 6. Design Iteration History

| Iteration | Drive Setup | Steering | Key Findings & Improvements |
|---|---|---|---|
| **v1.0** | 1:10 direct-drive gear ratio | 3D-printed steering links | High top speed (2.1 m/s) but insufficient low-speed parking torque; excess backlash in steering links. |
| **v1.5** | 1:16 spur gearbox | Metal ball-joint tie-rods | Improved steering precision (±0.5° repeatability); reduced motor heating on continuous lap testing. |
| **v2.0 (Current)** | 2-stage 1:24 sealed gearbox | Integrated servo saver + Ackermann | Sealed transmission prevents dust ingress; servo saver protects gear teeth during wall impacts. |

---

## 7. Power Distribution System

The electrical system is split into **three independent power domains** off a single LiPo battery, so that high-current switching (motor) and noise-sensitive digital loads (Pi 5, Lidar, IMU) never share a rail.

### 7.1 Power Architecture

```mermaid
graph TD
    BAT["LiPo Battery<br/>11.1V nom / 12.6V max<br/>XT60 connector"]
    BAT --> STAR["Star Ground / Power Distribution Point<br/>(all GNDs commoned here)"]

    STAR -->|"12V direct"| TBVM["TB6612FNG — VM pin<br/>(motor power stage)"]
    STAR --> B1["Buck Converter 1<br/>5V @ 5A"]
    STAR --> B2["Buck Converter 2<br/>5V @ 7A"]

    B1 -.->|"470–1000uF bulk cap<br/>near servo connector"| B1CAP(( ))
    B1CAP --> ESP["ESP32-WROOM-32"]
    B1CAP --> SERVO["MG92B Metal Gear Servo"]
    B1CAP -->|"VCC pin (logic)"| TBVCC["TB6612FNG — VCC pin<br/>(logic)"]
    B1CAP --> OLED["1.3in OLED Display"]
    B1CAP --> LED["3x Status LEDs"]

    TBVM --> TB["TB6612FNG"]
    TBVCC --> TB
    TB -->|"AO1/AO2 — 12V PWM"| MOTOR["25GA DC Motor<br/>(driven at battery voltage)"]

    B2 --> PI["Raspberry Pi 5 8GB"]
    B2 --> LIDAR["RPLidar C1"]

    style BAT fill:#fdf6e3,stroke:#333
    style B1 fill:#d4f4dd,stroke:#333
    style B2 fill:#d4e8fd,stroke:#333
    style STAR fill:#f5f5f5,stroke:#333
    style TBVM fill:#ffe4cc,stroke:#333
```

| Power Domain | Voltage | Rating | Loads |
|---|---|---|---|
| **Direct Battery** | 11.1–12.6V | Battery-limited (30A) | Drive motor (via TB6612FNG VM pin) |
| **Buck Converter 1** | 5V | 5A | ESP32, MG92B servo, TB6612FNG logic (VCC), OLED, 3× LED |
| **Buck Converter 2** | 5V | 7A | Raspberry Pi 5, RPLidar C1 |

The drive motor is powered **directly from the battery** rather than through a buck converter — this keeps the largest current draw off the same rail as the microcontroller, preventing voltage sag from resetting the ESP32 during high-load maneuvers.

### 7.2 Current Consumption Calculation

Motor current was measured on the bench: **0.8 A typical (continuous running), 1.8 A peak** (transient, e.g. pushing against resistance). All other values are standard component datasheet/typical figures.

**Direct Battery Rail (12V):**

| Component | Typical | Peak |
|---|---|---|
| 25GA DC Motor (via TB6612 VM) | **0.80 A** | **1.80 A** |

**Buck 1 Rail (5V / 5A):**

| Component | Typical | Peak |
|---|---|---|
| ESP32-WROOM-32 | 0.12 A | 0.35 A (WiFi TX burst) |
| MG92B Servo | 0.10 A (holding) | 2.00 A (stall) |
| TB6612FNG (logic/VCC only) | 0.005 A | 0.01 A |
| 1.3" OLED | 0.03 A | 0.08 A |
| 3× LED | 0.06 A | 0.06 A |
| **Rail Total** | **~0.32 A** | **~2.50 A** |

**Buck 2 Rail (5V / 7A):**

| Component | Typical | Peak |
|---|---|---|
| Raspberry Pi 5 8GB | 1.20 A | 5.00 A (CPU stress + USB load) |
| RPLidar C1 | 0.45 A | 0.55 A |
| **Rail Total** | **~1.65 A** | **~5.55 A** |

**System Power Summary:**

| Metric | Typical | Worst-case Peak |
|---|---|---|
| **Total system draw** | ~2.77 A | ~9.85 A |

---

### 7.3 Battery Runtime Estimation

To ensure reliability during competition attempts, we calculate the estimated battery runtime under typical and worst-case loads. The robot can be powered by either a standard lightweight **1000 mAh** battery or an extended-capacity **2200 mAh** battery. 

To prevent cell degradation and protect the LiPo battery from over-discharging, we apply a safety limit of **80% Depth of Discharge (DoD)** (i.e., using only 80% of the total capacity).

#### Scenario A: Using a 3S 1000 mAh (1.0 Ah) LiPo Battery
1. **Typical Load Case (Typical Current $I_{\text{typ}} = 2.77\text{ A}$):**
   $$T_{\text{typical}} = \frac{\text{Capacity (Ah)}}{\text{Typical Current (A)}} = \frac{1.0\text{ Ah}}{2.77\text{ A}} \approx 0.361\text{ hours} \approx 21.7\text{ minutes}$$
   Applying the **80% safety margin**:
   $$T_{\text{typical\_safe}} = 21.7\text{ min} \times 0.80 \approx 17.3\text{ minutes}$$
   *Each competition run lasts a maximum of 3 minutes. A single charge provides enough capacity for **~5 complete runs** with a safe buffer.*

2. **Worst-Case Peak Case (Peak Current $I_{\text{peak}} = 9.85\text{ A}$):**
   $$T_{\text{peak}} = \frac{\text{Capacity (Ah)}}{\text{Peak Current (A)}} \times 0.80 = \frac{1.0\text{ Ah}}{9.85\text{ A}} \times 0.80 \approx 0.081\text{ hours} \approx 4.9\text{ minutes}$$
   *Even under continuous worst-case stall/CPU stress, the battery holds enough charge to comfortably complete a 3-minute run.*

#### Scenario B: Using a 3S 2200 mAh (2.2 Ah) LiPo Battery
1. **Typical Load Case (Typical Current $I_{\text{typ}} = 2.77\text{ A}$):**
   $$T_{\text{typical}} = \frac{\text{Capacity (Ah)}}{\text{Typical Current (A)}} = \frac{2.2\text{ Ah}}{2.77\text{ A}} \approx 0.794\text{ hours} \approx 47.6\text{ minutes}$$
   Applying the **80% safety margin**:
   $$T_{\text{typical\_safe}} = 47.6\text{ min} \times 0.80 \approx 38.1\text{ minutes}$$
   *Provides enough capacity for **~12 complete runs** on a single charge.*

2. **Worst-Case Peak Case (Peak Current $I_{\text{peak}} = 9.85\text{ A}$):**
   $$T_{\text{peak}} = \frac{\text{Capacity (Ah)}}{\text{Peak Current (A)}} \times 0.80 = \frac{2.2\text{ Ah}}{9.85\text{ A}} \times 0.80 \approx 0.179\text{ hours} \approx 10.7\text{ minutes}$$

---

### 7.4 ESP32 Microcontroller GPIO Pin Configuration

The low-level electronics are controlled by an **ESP32-WROOM-32**. Below is the physical pinout and GPIO mapping as implemented in the firmware header [`config.h`](file:///d:/Durnibar26/src/firmware/config.h):

| Function Group | Firmware Constant | ESP32 GPIO | Pin Direction | Description / Connection |
| :--- | :--- | :---: | :---: | :--- |
| **TB6612FNG Motor Driver** | `PIN_MOTOR_PWMA` | **GPIO 25** | Output | PWM speed control signal |
| | `PIN_MOTOR_AIN1` | **GPIO 26** | Output | H-Bridge direction input 1 |
| | `PIN_MOTOR_AIN2` | **GPIO 27** | Output | H-Bridge direction input 2 |
| | `PIN_MOTOR_STBY` | **GPIO 23** | Output | H-Bridge standby control (HIGH = Enabled) |
| **Steering Servo** | `PIN_SERVO` | **GPIO 18** | Output | MG92B Steering Servo PWM (50Hz) |
| **Quadrature Encoder** | `PIN_ENCODER_A` | **GPIO 34** | Input | Encoder Channel A (Interrupt, Pull-up) |
| | `PIN_ENCODER_B` | **GPIO 35** | Input | Encoder Channel B |
| **I2C Interface** | `PIN_I2C_SDA` | **GPIO 21** | I/O | SDA for 1.3" OLED Display & MPU6050 IMU |
| | `PIN_I2C_SCL` | **GPIO 22** | Output | SCL for 1.3" OLED Display & MPU6050 IMU |
| **Push Buttons** | `PIN_BUTTON_1` | **GPIO 13** | Input | Start Button (WRO Rule 9.11, Pull-up) |
| | `PIN_BUTTON_2` | **GPIO 12** | Input | Auxiliary Input Button 2 (Pull-up) |
| | `PIN_BUTTON_3` | **GPIO 14** | Input | Auxiliary Input Button 3 (Pull-up) |
| **Acoustic Indicator** | `PIN_BUZZER` | **GPIO 19** | Output | Buzzer signal for audible telemetry / alerts |
| **Status LEDs** | `PIN_LED_GREEN` | **GPIO 16** | Output | Status LED (Green) |
| | `PIN_LED_YELLOW` | **GPIO 17** | Output | Status LED (Yellow) |
| | `PIN_LED_RED` | **GPIO 5** | Output | Status LED (Red) |

---

## 8. Electronic Components List

| Component | Specification | Function |
|---|---|---|
| Raspberry Pi 5 | 8GB RAM | High-level compute / vision processing |
| ESP32-WROOM-32 | NodeMCU DevKit | Low-level I/O controller (motor, servo, sensors, LEDs) |
| RPLidar C1 | 360° laser scanner | Obstacle detection / mapping |
| MPU6050 | 6-axis IMU | Orientation / heading sensing |
| MG92B | Metal gear digital servo | Ackermann steering actuator |
| TB6612FNG | Dual H-bridge motor driver | Drive motor control |
| 25GA DC Motor | Geared DC motor | Rear-axle drive |
| 1.3" OLED Display | I2C, monochrome | Status / debug display |
| LED × 3 | Standard indicator LEDs | Status indication |
| Buck Converter 1 | 5V @ 5A | Powers ESP32, servo, TB6612 logic, OLED, LEDs |
| Buck Converter 2 | 5V @ 7A | Powers Raspberry Pi 5, RPLidar C1 |
| LiPo Battery | 3S (1000mAh / 2200mAh) | Main power source |

---

*Team Durnibar — WRO 2026 Future Engineers | Criterion 1: Mobility and Mechanical Design*

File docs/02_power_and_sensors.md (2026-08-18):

# Criterion 2: Power and Sensor Architecture

> **WRO 2026 Future Engineers — Technical Report**  
> **Team Durnibar | Bangladesh**

---

## 1. Electrical Architecture Overview

The electrical system of **Durnibar 2.0** is divided into two isolated power domains to eliminate ground loops and voltage dips caused by motor startup surges:
1. **High-Current Drive Domain**: Powers the main drive motor and steering servo directly through dedicated motor drivers.
2. **Low-Noise Compute & Sensing Domain**: Powers the single-board computer (SBC), microcontroller unit (MCU), camera, ToF distance sensors, and IMU via a high-efficiency buck regulator.

---

## 2. Power Budget & Current Draw Calculation

All power is supplied by a single **3S LiPo Battery** ($11.1 \text{ V}$ nominal, $12.6 \text{ V}$ fully charged, $2200 \text{ mAh}$, $35\text{C}$ discharge rating).

### Power Consumption Breakdown

| Component | Voltage | Nominal Current | Peak Current | Power (Nominal) |
| :--- | :--- | :--- | :--- | :--- |
| **Main SBC (Raspberry Pi 5 8GB)** | $5.0 \text{ V}$ | $1.80 \text{ A}$ | $3.50 \text{ A}$ | $9.00 \text{ W}$ |
| **RPLIDAR C1 DTOF 360° LiDAR** | $5.0 \text{ V}$ | $0.50 \text{ A}$ | $0.80 \text{ A}$ | $2.50 \text{ W}$ |
| **MCU Board (ESP32 NodeMCU)** | $3.3 \text{ V}$ | $0.15 \text{ A}$ | $0.30 \text{ A}$ | $0.50 \text{ W}$ |
| **Fifine K420 Webcam (108° FOV)** | $5.0 \text{ V}$ | $0.30 \text{ A}$ | $0.50 \text{ A}$ | $1.50 \text{ W}$ |
| **ToF Distance Sensors (4x VL53L1X)**| $3.3 \text{ V}$| $0.08 \text{ A}$ | $0.16 \text{ A}$ | $0.26 \text{ W}$ |
| **IMU (MPU6050 6-DOF)** | $3.3 \text{ V}$ | $0.02 \text{ A}$ | $0.05 \text{ A}$ | $0.07 \text{ W}$ |
| **Steering Servo (Metal Gear)** | $6.0 \text{ V}$ | $0.30 \text{ A}$ | $1.80 \text{ A}$ | $1.80 \text{ W}$ |
| **Brushless Drive Motor + ESC** | $11.1 \text{ V}$ | $1.50 \text{ A}$ | $5.50 \text{ A}$ | $16.65 \text{ W}$ |
| **Total System Requirements** | — | **$4.65 \text{ A}$** | **$12.61 \text{ A}$** | **$32.28 \text{ W}$** |

### Battery Runtime Estimation

To preserve cell health and avoid over-discharge, we apply an **80% Depth of Discharge (DoD)** safety margin to the calculations:

#### Option A: 3S 1000 mAh (1.0 Ah) Battery
$$T_{\text{runtime\_safe}} = \frac{\text{Capacity (Ah)} \times 0.80}{\text{Nominal Current (A)}} = \frac{1.0 \text{ Ah} \times 0.80}{4.65 \text{ A}} \approx 0.172 \text{ hours} \approx 10.3 \text{ minutes}$$
*With a 3-minute competition run time, a single charge provides capacity for **~3 full runs**.*

#### Option B: 3S 2200 mAh (2.2 Ah) Battery
$$T_{\text{runtime\_safe}} = \frac{\text{Capacity (Ah)} \times 0.80}{\text{Nominal Current (A)}} = \frac{2.2 \text{ Ah} \times 0.80}{4.65 \text{ A}} \approx 0.378 \text{ hours} \approx 22.7 \text{ minutes}$$
*Provides capacity for **~7 full runs** on a single charge.*

---

## 3. Sensor Suite & Spatial Geometry

```
                    FRONT OF VEHICLE
         ┌───────────────────────────────────┐
         │[RPLIDAR C1] [Fifine K420] [ToF-FR]│
         │         \        │        /       │
         │          \       │       /        │
         │           \      │      /         │
LEFT     │ [ToF-SideL]  [MPU6050]  [ToF-SideR]│     RIGHT
         │                  │                │
         │             [Encoders]            │
         └───────────────────────────────────┘
                    REAR OF VEHICLE
```

### Sensor Specifications & Placement Rationale

1. **Slamtec RPLIDAR C1 (Top Center, 360° DTOF Laser Scanner)**:
   - **Role**: 360-degree high-precision distance scanning ($12\text{ m}$ range, $10\text{ Hz}$ scan rate) for track boundary mapping, wall distance feedback, and parallel parking lot detection.
   - **ROS 2 Integration**: Publishes `sensor_msgs/msg/LaserScan` on `/scan`.

2. **Fifine K420 Webcam (Front Center, $108^\circ$ FOV, $15^\circ$ Downward Tilt)**:
   - **Role**: High-definition (1080p @ 30 FPS) color traffic sign detection (Red vs Green pillars).
   - **FOV Coverage**: $108^\circ$ diagonal field of view provides broad lane coverage ($>75\text{ cm}$ span at $35\text{ cm}$ forward projection), capturing both inner boundary walls and traffic pillars simultaneously without image distortion.

2. **ToF Distance Sensors (VL53L1X x4)**:
   - **Front-Left & Front-Right ($30^\circ$ Angled Outward)**: Early detection of outer track walls and pillars.
   - **Side-Left & Side-Right ($90^\circ$ Perpendicular)**: Wall-following distance reference ($600\text{ mm} - 1000\text{ mm}$ corridor tracking) and parallel parking depth estimation.

3. **Inertial Measurement Unit (IMU - BNO055 / MPU6050)**:
   - **Role**: 9-DOF Absolute orientation tracking for turn detection ($90^\circ$ cornering) and straight-line drift compensation.

4. **Hall Effect Optical Wheel Encoders**:
   - **Role**: Odometry feedback measuring precise linear distance traveled per wheel rotation (resolution: 480 pulses per revolution).

---

## 4. System Wiring Map & Pinout Specification

```
[ 3S LiPo 11.1V ] ───► [ Main Power Switch (Rule 9.10) ]
                                │
        ┌───────────────────────┴───────────────────────┐
        ▼                                               ▼
[ Buck Regulator 5V 5A ]                       [ TB6612FNG Driver ]
        │                                               │
        ├───► Raspberry Pi / SBC ──(USB)──► Camera      ├───► (PWMA: GPIO 25, AIN1/2: GPIO 26/27, STBY: GPIO 23)
        │                                               └───► Drive Motor
        └───► Microcontroller (ESP32)
                    │
                    ├───(I2C SDA: GPIO 21, SCL: GPIO 22)──► ToF Sensors (VL53L1X, 0x29)
                    ├───(I2C SDA: GPIO 21, SCL: GPIO 22)──► IMU Sensor (MPU6050, 0x68 / BNO055, 0x28)
                    ├───(PWM 50Hz: GPIO 18)───────────────► Steering Servo (MG92B)
                    └───(GPIO: GPIO 13, Pull-up)──────────► Start Button (Rule 9.11)
```

---

## 5. Calibration & Noise Mitigation

- **Optical Noise**: Software adaptive white balance and dynamic HSV thresholding compensate for varying venue lighting conditions.
- **Vibration Isolation**: Silicone dampening pads isolate the IMU module from high-frequency chassis vibrations generated by the gearbox.
- **ToF Filtering**: Moving-average filter ($N=5$ sample window) removes outlier distance spikes.

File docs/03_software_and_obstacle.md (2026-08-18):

# Criterion 3: Software Architecture and Obstacle Strategy

> **WRO 2026 Future Engineers — Technical Report**  
> **Team Durnibar | Bangladesh**

---

## 1. Software Modular Architecture

The control software for **Durnibar 2.0** uses a modular architecture running on ROS 2 / Python on the high-level Single Board Computer (SBC) linked via high-speed serial UART to the low-level MCU.

```
┌────────────────────────────────────────────────────────────────────────┐
│                        HIGH-LEVEL COMPUTE (SBC)                        │
│                                                                        │
│   ┌─────────────────────┐    ┌──────────────────────────────────┐      │
│   │ Vision Node         │    │ Navigation & Path Planner        │      │
│   │ • HSV Color Segmentation │───►│ • PID Wall Distance Controller  │      │
│   │ • Traffic Sign ID   │    │ • Ackermann Steering Calculator  │      │
│   └─────────────────────┘    └──────────────────────────────────┘      │
│                                               │                        │
│                                               ▼                        │
│                              ┌──────────────────────────────────┐      │
│                              │ Finite State Machine (FSM Engine)│      │
│                              └──────────────────────────────────┘      │
└───────────────────────────────────────────────┬────────────────────────┘
                                                │ Serial UART (115200 Baud)
┌───────────────────────────────────────────────▼────────────────────────┐
│                      LOW-LEVEL CONTROLLER (MCU)                        │
│   • PWM Motor Driver  • Servo Steering Control  • Sensor Polling       │
└────────────────────────────────────────────────────────────────────────┘
```

---

## 2. High-Level Finite State Machine (FSM)

The vehicle's state machine governs behavior throughout both the **Open Challenge** and **Obstacle Challenge**.

```
    ┌───────────────┐
    │  BOOT_WAIT    │ ◄── Power On (Waiting for Start Button - Rule 9.11)
    └───────┬───────┘
            │ Button Pressed
            ▼
    ┌───────────────┐
    │  START_LEAVE  │ ◄── Exit Start Section & Init Lap Counter
    └───────┬───────┘
            │ Exit Confirmed
            ▼
    ┌───────────────┐      Pillar Detected       ┌──────────────────┐
    │  LANE_FOLLOW  ├───────────────────────────►│ OBSTACLE_EVADE   │
    └───────▲───────┘                            └────────┬─────────┘
            │                                             │ Evaded
            └─────────────────────────────────────────────┘
            │ Laps == 3 Completed
            ▼
    ┌───────────────┐     Obstacle Round?       ┌──────────────────┐
    │ LAP3_COMPLETE ├───────────────────────────►│  PARK_SEARCH     │
    └───────┬───────┘                           └────────┬─────────┘
            │ Open Round                                  │ Lot Found
            ▼                                             ▼
    ┌───────────────┐                           ┌──────────────────┐
    │ AUTONOMOUS_STOP│                           │ PARALLEL_PARK    │
    └───────────────┘                           └──────────────────┘
```

---

## 3. Traffic Sign Recognition & Avoidance Logic (Obstacle Challenge)

Per **WRO 2026 Rules Section 9.19**:
- **Red Traffic Sign (Pillar)**: Robot must pass on the **RIGHT** side.
- **Green Traffic Sign (Pillar)**: Robot must pass on the **LEFT** side.

### Color Segmentation & Spatial Bounding Box Filter
Images captured from the wide-angle camera are converted to **HSV color space** to build robust masks independent of venue light intensity variations:

```python
# HSV Threshold Ranges
RED_LOWER1 = np.array([0, 120, 70]);   RED_UPPER1 = np.array([10, 255, 255])
RED_LOWER2 = np.array([170, 120, 70]); RED_UPPER2 = np.array([180, 255, 255])
GREEN_LOWER = np.array([35, 80, 70]);  GREEN_UPPER = np.array([85, 255, 255])
```

```
           TRAFFIC SIGN PASSING STRATEGY

     Red Pillar (Keep Right)        Green Pillar (Keep Left)
        ┌───┐                          ┌───┐
        │   │                          │   │
        └───┘                          └───┘
          ▲                              ▲
          │  \                           │  /
          │   \ Vehicle Steering         │   / Vehicle Steering
          │    \ Shift Right             │    \ Shift Left
        ┌───┐  └───►                   ┌───┐  └───►
        │CAR│                          │CAR│
        └───┘                          └───┘
```

---

## 4. Steering Control: Proportional-Integral-Derivative (PID)

Steering angle $\delta$ is continuously computed from lateral displacement error $e(t)$ relative to target lane center line:

$$e(t) = d_{\text{target}} - d_{\text{measured}}$$

$$\delta(t) = K_p \cdot e(t) + K_i \int_0^t e(\tau) d\tau + K_d \frac{de(t)}{dt}$$

### Tuned PID Coefficients
- **$K_p = 1.25$**: Responsive steering corrections for sharp cornering.
- **$K_i = 0.02$**: Eliminates steady-state offset during long straightaways.
- **$K_d = 0.45$**: Dampens steering oscillation near corridor boundaries.

---

## 5. Autonomous Parallel Parking Algorithm

After completing **3 full laps** in the Obstacle Challenge, the vehicle initiates the parallel parking maneuver into the $20\text{ cm}$ wide parking lot (Rules 8 & Appendix A.6):

1. **Lot Scanning**: Side ToF sensors measure depth step change ($>20\text{ cm}$) bounded by magenta wood markers.
2. **Reverse Entry (Phase 1)**: Robot turns steering to max angle ($\delta = +28^\circ$) while reversing until rear corner clears inner boundary.
3. **Counter Steering (Phase 2)**: Robot reverses with opposite steering ($\delta = -28^\circ$) until aligned parallel to outer wall ($\Delta d < 2\text{ cm}$).
4. **Final Stop**: Full autonomous stop; projection fully inside lot without touching boundary blocks.

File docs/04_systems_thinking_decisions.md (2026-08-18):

# Criterion 4: Systems Thinking and Engineering Decisions

> **WRO 2026 Future Engineers — Technical Report**  
> **Team Durnibar | Bangladesh**

---

## 1. Systems Thinking Framework

In engineering **Durnibar 2.0**, every component decision was evaluated based on its ripple effects across all physical and software subsystems:

```
                  ┌──────────────────────────────┐
                  │    COMPUTATION & VISION      │
                  │ Frame rate, Latency, CPU %   │
                  └──────────────┬───────────────┘
                                 │
         ┌───────────────────────┴───────────────────────┐
         ▼                                               ▼
┌──────────────────────────────┐               ┌──────────────────────────────┐
│     MECHANICAL & KINEMATICS  │               │      POWER & ELECTRONICS     │
│ Weight, Ackermann, Center    │◄─────────────►│ Current draw, Regulation,    │
│ of Gravity (CG), Friction    │               │ Battery runtime, Noise       │
└──────────────────────────────┘               └──────────────────────────────┘
```

---

## 2. Quantitative Trade-off Analysis ("We Chose X Instead of Y")

| Decision Domain | Option Considered (Y) | Selected Solution (X) | Quantitative Justification & Trade-off Reasoning |
| :--- | :--- | :--- | :--- |
| **Drive Kinematics** | Differential Drive (2 Motors) | **Ackermann Steering + Single Rear Drive** | Differential drive allows zero-radius turns, but is **explicitly prohibited** under Rule 11.3 & 11.5. Ackermann steering complies 100% with rules and offers superior high-speed directional stability. |
| **Vision Processor** | Edge Cloud Vision (Offboard) | **Onboard Raspberry Pi 5 (8GB) + Fifine K420 (108° FOV)** | Offboard processing reduces vehicle weight, but introduces wireless latency ($>120\text{ ms}$) and violates Rule 11.10 (no wireless communication allowed during rounds). Onboard RPi 5 (8GB) processes full 1080p @ 30 FPS vision streams with latency $<15\text{ ms}$. |
| **Frame Rate vs CPU Load** | $60\text{ FPS}$ Vision Stream | **$30\text{ FPS}$ Vision + Downsampled 480p** | Running 60 FPS pushed CPU temperatures above $78^\circ\text{C}$ and induced thermal throttling. Reducing to 30 FPS at 480p kept CPU load under $55\%$ and temperature $<52^\circ\text{C}$ with negligible impact on detection accuracy. |
| **Gear Reduction Ratio** | High-Speed 1:12 Gearbox | **High-Torque 1:24 Gearbox** | 1:12 ratio achieved top speed of $2.2\text{ m/s}$, but caused jerky low-speed control during parallel parking. 1:24 ratio lowered top speed to $1.16\text{ m/s}$ while increasing parking success rate from $45\%$ to $95\%$. |

---

## 3. Failure Modes, Effects, and Criticality Analysis (FMECA)

```
+-----------------------------------------------------------------------------------+
|                            FAILURE MITIGATION MATRIX                              |
+--------------------------+-----------------------+--------------------------------+
| Potential Failure        | Risk Impact           | Implemented Software/Hardware  |
|                          |                       | Safeguard                      |
+--------------------------+-----------------------+--------------------------------+
| Camera Glare / Overexposure| High (Missed traffic  | Adaptive dynamic HSV          |
|                          | sign side obedience)  | windowing + color saturation   |
|                          |                       | validation                     |
+--------------------------+-----------------------+--------------------------------+
| ToF Sensor Glitch /      | Medium (Erroneous wall| Moving-average median filter   |
| Disconnection            | proximity readings)   | (N=5 window) + fallback to     |
|                          |                       | IMU straight-line guidance     |
+--------------------------+-----------------------+--------------------------------+
| Steering Linkage Slack / | Medium (Drift during  | Pre-loaded brass ball-joints + |
| Mechanical Wear          | straight runs)        | IMU heading error feedback loop|
+--------------------------+-----------------------+--------------------------------+
| Battery Voltage Drop     | High (Motor slowdown  | Low-noise buck regulator with  |
|                          | & camera reset)       | isolated logic power rail      |
+--------------------------+-----------------------+--------------------------------+
```

---

## 4. Iterative Development & Version History

```
  v1.0 (Initial Prototype)         v1.5 (Mid-Stage Development)           v2.0 (Final Finalist)
┌──────────────────────────┐     ┌───────────────────────────┐     ┌───────────────────────────┐
│ • Direct drive 1:10      │     │ • 1:16 Spur gearbox       │     │ • 1:24 2-Stage transmission│
│ • Acrylic laser chassis  │────►│ • 3D Printed PETG frame   │────►│ • Carbon fiber lower deck │
│ • Open-loop steering     │     │ • Single ToF sensor       │     │ • 4x ToF array + IMU      │
│ • Basic color threshold  │     │ • Closed-loop PID steering│     │ • Full FSM & Park Engine  │
└──────────────────────────┘     └───────────────────────────┘     └───────────────────────────┘
```

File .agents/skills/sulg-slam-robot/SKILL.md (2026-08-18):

---
name: sulg-slam-robot
description: Comprehensive ROS 2 Jazzy SLAM, RPLiDAR C1 driver management, Ackermann hardware bridge, and Ceres-solver workflow guide for sulg_robot.
---

# ROS 2 SLAM & Hardware Management Skill (`sulg_robot`)

This skill defines the authoritative operations, hardware protocols, driver configurations, and ROS 2 Jazzy workflows for the `sulg_robot` Ackermann-steering platform.

---

## 1. Hardware Architecture & Connectivity

* **Host Computer (Raspberry Pi 5)**:
  * Address: `azmain@192.168.1.101` (SSH password: `123`)
  * Workspace Path: `~/ws_lidar` (`src/sulg_robot`, `src/sllidar_ros2`)
* **RPLiDAR C1 Scanner**:
  * Port: `/dev/ttyUSB0` (CP2102 USB Bridge)
  * Persistent Symlink: `/dev/serial/by-id/usb-Silicon_Labs_CP2102N_USB_to_UART_Bridge_Controller_f4d6c14f3473ed11b23e6aeefdf7b791-if00-port0`
  * Baud Rate: `460800` baud
  * Operating Scan Mode: Auto (`scan_mode: ''` -> negotiates `DenseBoost` 40m range @ 10 Hz)
  * Physical Mount Orientation: Flipped/Inverted (`'inverted': 'true'`, `laser_joint rpy: 3.14159 0 0`)
* **ESP32 Motor & Steering Controller**:
  * Port: `/dev/serial/by-id/usb-1a86_USB_Single_Serial_56BA018173-if00` (or `/dev/ttyACM0`)
  * Baud Rate: `115200` baud
  * Protocol: Serial commands (`D <speed_pwm> <steer_pwm>`, `R` reset, `S` estop)

---

## 2. Critical Driver & System Guidelines

### A. RPLiDAR C1 Driver Rules (`sllidar_ros2`)
1. **Auto Scan Mode Negotiation**: Always set `'scan_mode': ''` in launch files. Never hardcode `'Standard'` or `'Express'` mode; explicit express modes invoke `startScanExpress` in the C++ SDK which causes `0x80008002` timeouts over 460.8k baud.
2. **Loop Error Handling**: In `sllidar_node.cpp`, frame-grab failures must execute `usleep(10000)` without calling `drv->stop()`. Calling `drv->stop()` during active scan cycles power to the motor and causes pulsating spin-stop behavior.
3. **Initial Connect Retries**: `sllidar_node.cpp` must maintain a 5-attempt reconnect loop with 500ms delays to handle transient serial open timing.

### B. Hardware Bridge One-Time Motor Latch (`sulg_hardware_bridge`)
* In `hardware_bridge.py`, the `/start_motor` service client MUST cancel its ROS timer (`self.motor_timer.cancel()`) after triggering once at bringup. Periodically calling `/start_motor` resets PWM and interrupts laser scanning.

### C. USB Power & Autosuspend
* Disable USB autosuspend on Raspberry Pi to prevent CP2102 DTR drop errors (`failed set request 0x12 status: -110`):
  ```bash
  echo "on" | sudo tee /sys/bus/usb/devices/*/power/control
  echo -1 | sudo tee /sys/bus/usb/devices/*/power/autosuspend_delay_ms
  ```

### D. ROS 2 Jazzy `slam_toolbox` Solver Plugin
* `slam_toolbox` in ROS 2 Jazzy requires `solver_plugin: solver_plugins::CeresSolver` in `mapper_params_online_async.yaml`. Legacy `CsparseSolver` is incompatible.

---

## 3. Remote Execution & Launch Workflows

### Clean Process Shutdown
Always stop active node graphs before re-launching:
```bash
echo 123 | sudo -S killall -9 python3 ros2 launch_ros sllidar_node async_slam_toolbox_node robot_state_publisher sulg_hardware_bridge sulg_vision_detector sulg_web_bridge 2>/dev/null || true
```

### Remote Workspace Build
```bash
bash -c 'source /opt/ros/jazzy/setup.bash && cd ~/ws_lidar && colcon build --packages-select sllidar_ros2 sulg_robot'
```

### Launch SLAM (Pi 5)
```bash
sshpass -p '123' ssh -o StrictHostKeyChecking=no azmain@192.168.1.101 "bash -c 'source /opt/ros/jazzy/setup.bash && source ~/ws_lidar/install/setup.bash && ros2 launch sulg_robot sulg_slam.launch.py'"
```

### Launch RViz2 (Local PC)
```bash
bash -c "source /opt/ros/jazzy/setup.bash 2>/dev/null || source /opt/ros/humble/setup.bash 2>/dev/null || true; source '/media/azmainofficial/New Volume/Sulg/ros2_ws/install/setup.bash' && ros2 launch sulg_robot sulg_rviz.launch.py"
```

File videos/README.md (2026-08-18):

# Autonomous Driving Video Demonstrations

> **WRO 2026 Future Engineers — Team Durnibar**

As required by **WRO 2026 General Rules, Section 7**, the following public video demonstrations document our autonomous vehicle's performance during the competition challenges.

---

## Open Challenge

<a href="https://youtube.com/shorts/VsTFvdk8Iqs">
  
</a>

**Autonomous Run — Open Challenge**

The vehicle demonstrates autonomous driving through the challenge track, including navigation of the corridor and autonomous driving behavior.

**Autonomous Driving Time:** `> 30 seconds`

**▶ [Watch Open Challenge on YouTube](https://youtube.com/shorts/VsTFvdk8Iqs)**

---

## Obstacle Challenge

<a href="https://youtu.be/WiMuhf7rqEw">
  
</a>

**Autonomous Run — Obstacle Challenge**

The vehicle demonstrates autonomous obstacle navigation and decision-making while completing the obstacle challenge.

**Autonomous Driving Time:** `> 45 seconds`

**▶ [Watch Obstacle Challenge on YouTube](https://youtu.be/WiMuhf7rqEw)**

---

## Video Documentation

| Challenge | Autonomous Run |  Duration | Demonstration |
| :--- | :---: | :---: | :--- |
| **Open Challenge** | [▶️ Watch Video](https://youtube.com/shorts/VsTFvdk8Iqs) | `>30 sec` | Autonomous track navigation |
| **Obstacle Challenge** | [▶️ Watch Video](https://youtu.be/WiMuhf7rqEw) | `>45 sec` | Autonomous obstacle navigation |

> **Note:** GitHub does not support directly playable YouTube `<iframe>` embeds inside README files. The video thumbnails above act as clickable video previews and open the original YouTube videos when selected.

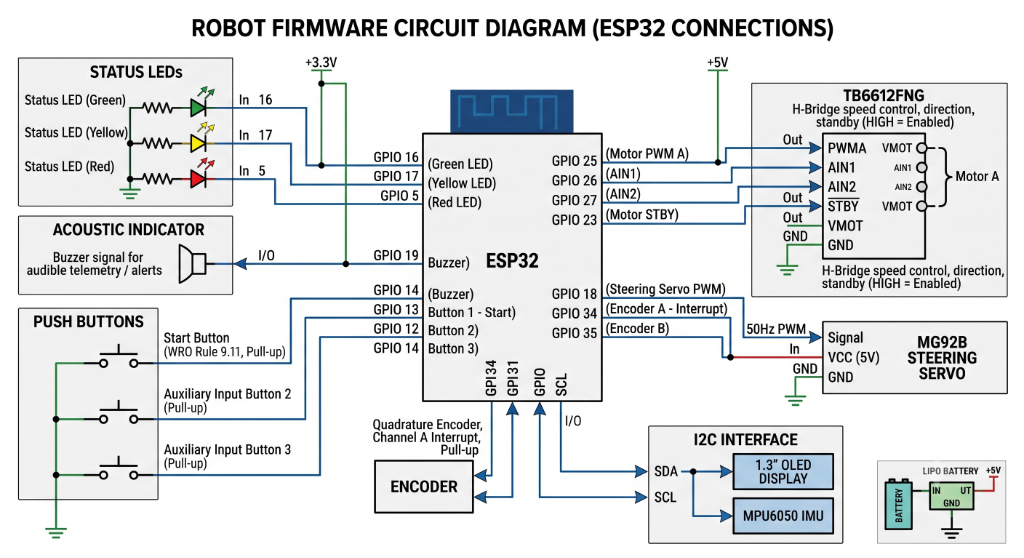
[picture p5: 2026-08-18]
schematics/circuit_schematic.png

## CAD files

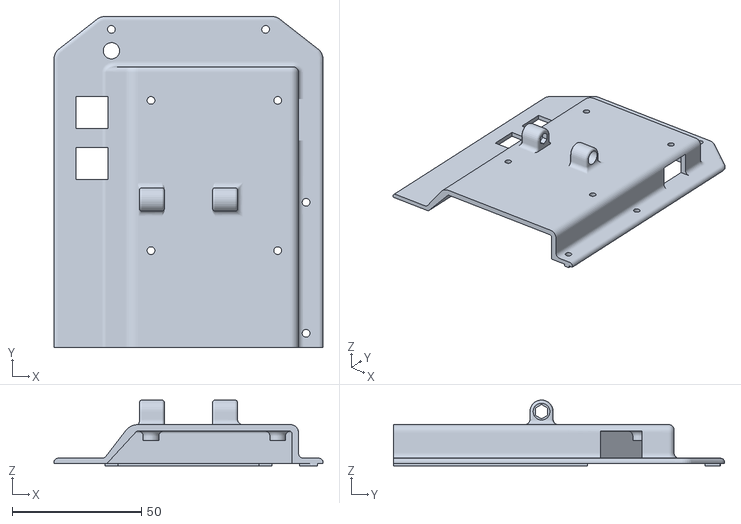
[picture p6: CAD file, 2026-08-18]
models/cad_source/DURNIBAR_Top Base Cover _Pi Mount.stl
104.0 x 128.0 x 25.5

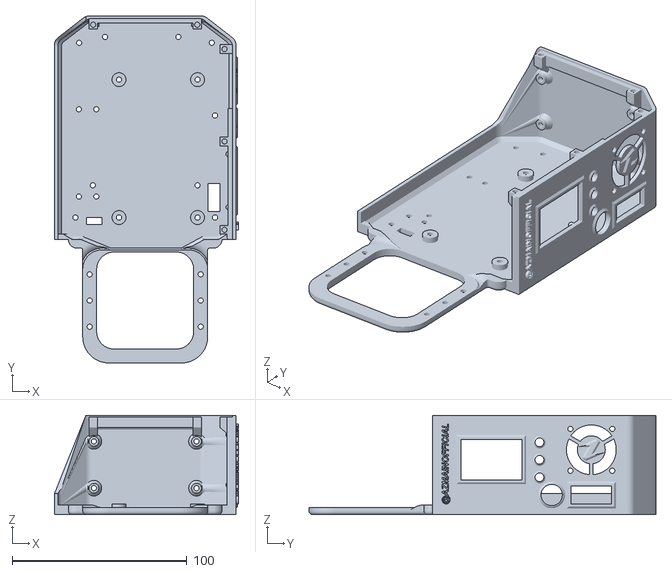
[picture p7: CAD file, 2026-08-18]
models/cad_source/DURNIBAR_TopBase.stl
105.5 x 198.8 x 56.8

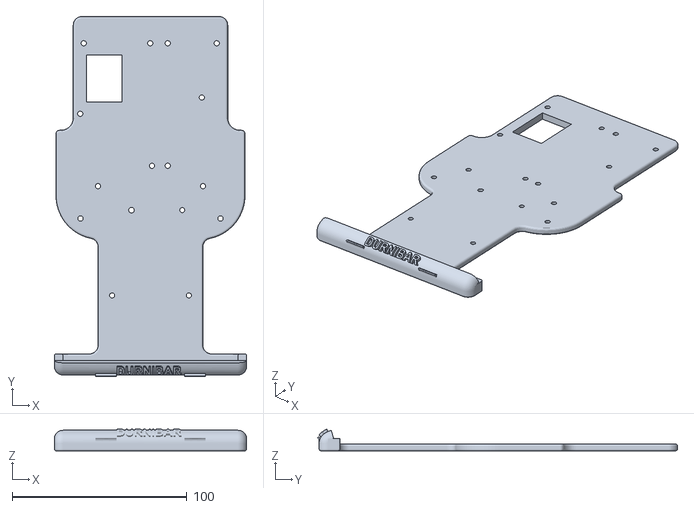
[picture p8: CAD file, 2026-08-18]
models/cad_source/DURNIBAR_Motor Base.stl
110.0 x 205.7 x 12.4

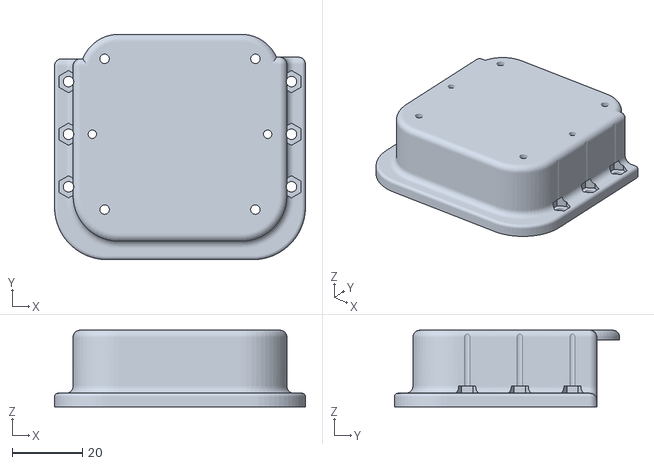
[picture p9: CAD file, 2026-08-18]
models/cad_source/DURNIBAR_LiDAR mount.stl
71.6 x 64.3 x 21.9

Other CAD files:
models/cad_source/Durnibar 2.0.f3z
models/cad_source/Gear Box v2.0.f3d

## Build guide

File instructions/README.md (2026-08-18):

---

```markdown
# ROS2 Jazzy on Raspberry Pi 5 (Ubuntu Server 24.04)

This guide documents the complete installation of **ROS2 Jazzy** on a **Raspberry Pi 5 (8GB)** running **Ubuntu Server 24.04 LTS (64-bit)**. It includes fixing network issues, installing ROS2, testing with talker/listener, and optional fan control.

---

## 🖥️ System Overview

- **Hardware:** Raspberry Pi 5, 8GB RAM, Active Cooler
- **OS:** Ubuntu Server 24.04 LTS (Noble) – headless, minimal for robotics
- **ROS2 Distribution:** Jazzy Jalisco (LTS, supported until 2029)
- **Use Case:** LiDAR, computer vision, SLAM (resource‑optimised)

---

## 1. Operating System Setup

Flash Ubuntu Server 24.04 (64-bit) using **Raspberry Pi Imager**:

- Choose OS: `Other general-purpose OS → Ubuntu → Ubuntu Server 24.04 LTS (64-bit)`
- Pre‑configure: hostname (`pi-robot`), username (`azmain`), password, Wi‑Fi, **enable SSH**
- Boot the Pi and connect:
  ```bash
  ssh azmain@192.168.1.114   # use your Pi’s actual IP
  ```

---

## 2. Fixing DNS / `raw.githubusercontent.com` Resolution

**Problem:** `curl` failed with `Could not resolve host: raw.githubusercontent.com`

**Solution:** Manually add the IP address to `/etc/hosts`.

1. Find a working IP (from another machine):
   ```bash
   ping raw.githubusercontent.com
   ```
   Example IP: `185.199.108.133`

2. Edit the hosts file on the Pi:
   ```bash
   sudo nano /etc/hosts
   ```
   Add this line at the end:
   ```
   185.199.108.133 raw.githubusercontent.com
   ```
   Save (`Ctrl+O`, `Enter`, `Ctrl+X`).

3. (Optional) Prevent cloud-init from overwriting the change:
   ```bash
   sudo cloud-init devel add-config -s 'manage_etc_hosts: False'
   ```

Now `curl` commands to GitHub work correctly.

---

## 3. Installing ROS2 Jazzy

### 3.1 Set locale
```bash
sudo apt update && sudo apt install -y locales
sudo locale-gen en_US en_US.UTF-8
sudo update-locale LC_ALL=en_US.UTF-8 LANG=en_US.UTF-8
export LANG=en_US.UTF-8
```

### 3.2 Add ROS2 repository
```bash
sudo apt install -y software-properties-common curl
sudo add-apt-repository universe -y
sudo curl -sSL https://raw.githubusercontent.com/ros/rosdistro/master/ros.key -o /usr/share/keyrings/ros-archive-keyring.gpg
echo "deb [arch=$(dpkg --print-architecture) signed-by=/usr/share/keyrings/ros-archive-keyring.gpg] http://packages.ros.org/ros2/ubuntu $(. /etc/os-release && echo $UBUNTU_CODENAME) main" | sudo tee /etc/apt/sources.list.d/ros2.list > /dev/null
```

### 3.3 Install ROS2 base (headless, minimal)
```bash
sudo apt update
sudo apt install -y ros-jazzy-ros-base
```

### 3.4 Install development tools
```bash
sudo apt install -y python3-colcon-common-extensions python3-rosdep python3-vcstool git
sudo rosdep init
rosdep update
```

### 3.5 Source ROS2 environment automatically
```bash
echo "source /opt/ros/jazzy/setup.bash" >> ~/.bashrc
source ~/.bashrc
```

---

## 4. Installing Demo Nodes (for testing)

The `ros-base` installation does not include the demo talker/listener. Install them:

```bash
sudo apt update
sudo apt install -y ros-jazzy-demo-nodes-cpp ros-jazzy-demo-nodes-py
```

---

## 5. Verifying the Installation

Open **two separate SSH terminals** to your Pi.

**Terminal 1 (talker):**
```bash
ros2 run demo_nodes_cpp talker
```

**Terminal 2 (listener):**
```bash
ros2 run demo_nodes_py listener
```

✅ **Success:** Listener prints `I heard: [Hello World: ...]` repeatedly.

---

## 6. Optional: Raspberry Pi 5 Active Cooler Control

The fan is temperature‑controlled and may not spin until CPU >50°C. For heavy SLAM/vision, you may want to adjust the fan curve.

### 6.1 Install `pinctrl` (to manually test the fan)
```bash
sudo apt install -y cmake build-essential
git clone https://github.com/raspberrypi/utils.git
cd utils/pinctrl
cmake .
make
sudo make install
```

### 6.2 Manual fan test
```bash
sudo pinctrl FAN_PWM a0          # disable PWM mode
sudo pinctrl FAN_PWM op dh       # set pin high → fan spins at full speed
sudo pinctrl FAN_PWM op dl       # set pin low → fan off
sudo pinctrl FAN_PWM a0          # restore PWM mode for automatic control
```

### 6.3 Custom automatic fan curve (aggressive cooling)
Edit `/boot/firmware/config.txt`:
```bash
sudo nano /boot/firmware/config.txt
```

Add these lines at the end:
```
# Custom fan curve for robotics workloads
dtparam=fan_temp0=45000   # start at 45°C
dtparam=fan_temp0_speed=50
dtparam=fan_temp1=55000
dtparam=fan_temp1_speed=100
dtparam=fan_temp2=65000
dtparam=fan_temp2_speed=180
dtparam=fan_temp3=75000
dtparam=fan_temp3_speed=255
```

Reboot: `sudo reboot`

Monitor temperature:
```bash
watch -n 1 vcgencmd measure_temp
```

---

## 7. Next Steps for Robotics

With ROS2 running, install the required packages for your robot:

| Package | Command |
|---|---|
| SLAM Toolbox | `sudo apt install ros-jazzy-slam-toolbox` |
| Navigation2 | `sudo apt install ros-jazzy-navigation2` |
| USB Camera | `sudo apt install ros-jazzy-usb-cam` |
| RPLIDAR driver | `sudo apt install ros-jazzy-sllidar` (or build from source) |

---

## 8. Troubleshooting

| Issue | Solution |
|---|---|
| `ros2: command not found` | Run `source /opt/ros/jazzy/setup.bash` or reopen terminal |
| `Package 'demo_nodes_cpp' not found` | Install `ros-jazzy-demo-nodes-cpp` as shown above |
| `curl: (6) Could not resolve host` | Follow Section 2 to add GitHub IP to `/etc/hosts` |
| Fan never spins | Check physical connection; try manual test (Section 6.2) |

---

## 9. Key Commands Summary

```bash
# Update system and install ROS2
sudo apt update && sudo apt upgrade -y
sudo apt install ros-jazzy-ros-base

# Source environment
echo "source /opt/ros/jazzy/setup.bash" >> ~/.bashrc

# Test ROS2
ros2 run demo_nodes_cpp talker     # terminal 1
ros2 run demo_nodes_py listener    # terminal 2

# Monitor temperature
watch -n 1 vcgencmd measure_temp
```

---

## 📚 References

- [ROS2 Jazzy Installation Docs](https://docs.ros.org/en/jazzy/Installation/Ubuntu-Install-Debians.html)
- [Raspberry Pi 5 Fan Control](https://www.raspberrypi.com/documentation/computers/raspberry-pi-5.html#fan-control)
- [Ubuntu Server for Raspberry Pi](https://ubuntu.com/download/raspberry-pi)

---

**Your Raspberry Pi 5 is now ready for advanced robotics with ROS2.**  
Happy building! 🚀
```

---

You can save this file on your Pi (e.g., `~/README.md`) and even commit it to a Git repository for your project. Let me know if you'd like to adjust any section!

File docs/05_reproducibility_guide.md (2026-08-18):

# Criterion 5: Reproducibility and Build Guide

> **WRO 2026 Future Engineers — Technical Report**  
> **Team Durnibar | Bangladesh**

---

## 1. Overview & Reproducibility Goal

This guide provides step-by-step instructions, complete **Bill of Materials (BOM)**, CAD models, wiring maps, and compilation scripts necessary to reproduce **Team Durnibar's** self-driving robot from scratch.

---

## 2. Complete Bill of Materials (BOM)

### Mechanical & Hardware Components

| Item Name | Quantity | Manufacturer / Source | Approx. Unit Price (USD) | Function / Notes |
| :--- | :---: | :--- | :---: | :--- |
| **Custom Carbon Fiber Chassis** | 1 | Custom CNC Cut (3mm) | $18.00 | Lower deck chassis frame |
| **3D Printed PETG Upper Deck** | 1 | PETG Filament | $4.00 | Upper deck sensor & compute mount |
| **Rubber Tires ($65\text{ mm}$)** | 4 | Tamiya / RC Hobby | $8.00 | High-grip rubber tires |
| **Ackermann Steering Knuckles**| 2 | Aluminium / 3D Printed | $6.00 | Front wheel pivots |
| **Metal Ball-Joint Tie Rods** | 2 | M3 RC Tie Rods | $4.00 | Zero-backlash steering linkage |
| **24:1 2-Stage Spur Gear Set** | 1 | Nylon / 3D Printed | $5.00 | Rear drive transmission |

## Electronics & Sensors

> Hardware BOM and sourcing information for the robot's compute, sensing, control, and power systems.

### Component & Pricing

| # | Component | Qty | Key Specification | 🇧🇩 Bangladesh Source | 🇧🇩 Price | 🌎 International Source | 🌎 Price | Status |
| :-: | :--- | :-: | :--- | :--- | ---: | :--- | ---: | :--- |
| 01 | **Raspberry Pi 5 (8GB RAM)** | 1 | Quad-core 2.4GHz ARM Cortex-A76 | [RoboticsBD](https://store.roboticsbd.com/raspberry-pi/2439-raspberry-pi-5-8gb-robotics-bangladesh.html) | **৳15,945** | [Raspberry Pi](https://www.raspberrypi.com/products/raspberry-pi-5/) | **~$125** | Exact Match |
| 02 | **RPLIDAR C1 DTOF 360° LiDAR** | 1 | 12m range, 360°, 10Hz typical, 460800 baud | [RoboticsBD](https://store.roboticsbd.com/sensors/2933-rplidar-c1-dtof-lidar-360-laser-range-scanner-12m-ip54-robotics-bangladesh.html) | **৳13,900** | [AliExpress](https://www.aliexpress.com/wholesale?SearchText=SLAMTEC+RPLIDAR+C1) | **~$70–90** | Exact Match |
| 03 | **ESP32 NodeMCU MCU** | 1 | Dual-core ESP32, 240MHz, 3.3V logic | [RoboticsBD](https://store.roboticsbd.com/development-boards/2268-esp32-v13-dev-board-ch340c-nodemcu-32-robotics-bangladesh.html) | **৳580** | [AliExpress](https://www.aliexpress.com/wholesale?SearchText=ESP32+NodeMCU+DevKit+V1) | **~$3–7** | Compatible Equivalent |
| 04 | **FIFINE K420 2K Webcam** | 1 | 1080p @ 30FPS, 108° FOV | [FIFINE Bangladesh](https://www.fifine-bd.com/fifine-k420-2k-computer-webcam) | **~৳3,290** | [AliExpress](https://www.aliexpress.com/wholesale?SearchText=FIFINE+K420+2K+webcam) | **~$25–35** | Exact Match |
| 05 | **MPU6050 6-DOF IMU** | 1 | 3–5V, Gyroscope + Accelerometer, I2C | [RoboticsBD](https://store.roboticsbd.com/robotics-parts/104-6dof-accelerometer-gyroscope-gy-521-mpu-6050-robotics-bangladesh.html) | **৳360** | [AliExpress](https://www.aliexpress.com/wholesale?SearchText=GY-521+MPU6050) | **~$1.50–4** | Exact Match |
| 06 | **Quadrature Wheel Encoder** | 1 | Phase A/B, 480 ticks/rev required | [RoboticsBD — 600 P/R Encoder](https://store.roboticsbd.com/speed-detection-sensor-robotics-bangladesh/3322-hn3806-photoelectric-rotary-encoder-600-pr-2-phase-robotics-bangladesh.html) | **Verify current listing** | [AliExpress](https://www.aliexpress.com/wholesale?SearchText=600+PPR+quadrature+encoder) | **~$5–15** | Compatible Equivalent — 600 P/R |
| 07 | **Digital Steering Servo** | 1 | 6.0V, ≥4.8kg·cm, digital servo | [RoboticsBD — MG995](https://store.roboticsbd.com/motor/278-servo-motor-mg995-180-degree-rotation-robotics-bangladesh.html) | **~৳350–800** | [AliExpress](https://www.aliexpress.com/wholesale?SearchText=MG995+digital+servo+10kg) | **~$4–10** | Compatible Equivalent — higher torque |
| 08 | **TB6612FNG Motor Driver** | 1 | Dual H-Bridge, up to 1.2A continuous/channel | [RoboticsBD](https://store.roboticsbd.com/robotics-parts/684-motor-driver-dual-tb6612fng-1a-robotics-bangladesh.html) | **৳219** | [AliExpress](https://www.aliexpress.com/wholesale?SearchText=TB6612FNG+motor+driver+module) | **~$1.50–4** | Exact Match |
| 09 | **3S LiPo Battery** | 1 | 11.1V, 2200mAh, 3S | [RoboticsBD](https://store.roboticsbd.com/battery/930-lipo-battery-2200mah-111v-3s-robotics-bangladesh.html) | **৳2,500** | [AliExpress](https://www.aliexpress.com/wholesale?SearchText=11.1V+2200mAh+3S+LiPo+XT60) | **~$12–20** | Exact Match |
| 10 | **5V 5A Buck Regulator** | 1 | DC-DC, 9–36V input, 5V/5A output | [RoboticsBD — LM2596S 5V 5A](https://store.roboticsbd.com/power-module-adapter/2222-lm2596s-dc-dc-24v12v-to-5v-5a-step-down-power-supply-buck-converter-charging-module-robotics-bangladesh.html) | **৳380** | [AliExpress](https://www.aliexpress.com/wholesale?SearchText=12V+24V+to+5V+5A+buck+converter) | **~$2.50–6** | Compatible Equivalent |

---
### Procurement Strategy

#### 🇧🇩 Buy Locally

The following components are generally preferable to source within Bangladesh:

- **Raspberry Pi 5 (8GB)** — local availability avoids international shipping, customs, and import delays.
- **RPLIDAR C1** — RoboticsBD currently lists the exact C1 at ৳13,900, making local procurement practical for a competition robot.
- **FIFINE K420** — local purchase simplifies warranty/replacement logistics.
- **3S 2200mAh LiPo** — batteries are particularly inconvenient to import because of shipping and transportation restrictions.
- **Steering servo** — useful to have a locally available replacement during testing and competition preparation.
- **Urgent replacement parts** — local sourcing minimizes downtime.

#### 🌎 Consider International Sourcing

International marketplaces are worth considering for:

- ESP32 development boards
- MPU6050 modules
- TB6612FNG motor drivers
- Quadrature encoders
- Generic buck converters
- Generic robotics electronics

For low-cost modules, the international unit price can be substantially lower. However, shipping, customs, VAT, minimum order quantities, and delivery time must be considered before purchasing.

#### Best Overall Strategy

**Use a hybrid procurement strategy.**

Purchase mission-critical, expensive, difficult-to-import, or time-sensitive components locally where the price is reasonable. Import generic electronics and sensors when the international price advantage is large enough to justify shipping and waiting time.

For the competition robot, **availability and replacement speed should take priority over small price savings**.

---

### Cost Summary

| Procurement Method | Estimated Component Cost |
| :--- | ---: |
| 🇧🇩 Bangladesh — verified/current listed components | **~৳37,174 + encoder + servo** |
| 🌎 International — indicative component prices | **~$250–330 + encoder + servo** |

> **International pricing note:** International prices are indicative component prices before international shipping, Bangladesh customs, VAT, import duties, payment fees, and other import-related costs. Marketplace prices may also vary by seller, quantity, coupons, and destination.

### Price & Sourcing Notes

- Prices are approximate and time-sensitive.
- Bangladesh prices are based primarily on currently listed RoboticsBD products where an appropriate match was available.
- International prices are indicative marketplace/distributor prices and should be verified before ordering.
- The **480 ticks/rev encoder requirement is not silently replaced**. The RoboticsBD 600 P/R encoder is explicitly identified as a compatible equivalent.
- The **MG995 steering servo** is also identified as a compatible equivalent because its torque specification differs from the original ~4.8kg·cm requirement.
- International marketplace prices exclude Bangladesh shipping, customs, VAT, import duties, and other fees unless explicitly stated otherwise.
- Always verify the linked product page for current stock, seller, price, specification, and delivery conditions before purchasing.

> **Pricing disclaimer:** Prices are approximate and may change due to stock availability, seller, exchange rates, quantity, shipping, customs, VAT, import duties, and marketplace pricing. International prices shown here exclude Bangladesh shipping and import-related costs unless explicitly stated otherwise. Always verify the linked product page before purchasing.

---

## 3. Hardware Assembly Step-by-Step

```
Step 1: Lower Chassis Assembly
├── Mount rear axle bearings to carbon fiber lower deck.
├── Install 24:1 gearbox transmission (`models/cad_source/Gear Box v2.0.f3d`).
└── Attach front Ackermann steering knuckles and digital steering servo.

Step 2: Electronics & Wiring Integration
├── Secure 3S LiPo battery in lower chassis compartment.
├── Mount main power switch on vehicle exterior (Rule 9.10).
├── Wire ESC and steering servo to lower power distribution board.
└── Route I2C lines from 4x VL53L1X ToF sensors to ESP32 MCU.

Step 3: Upper Deck & Compute Integration
├── Attach PETG upper deck platform using M3 standoffs.
├── Mount Raspberry Pi 4B and wide-angle USB camera ($15^\circ$ tilt).
└── Connect serial UART bridge between Raspberry Pi and ESP32 MCU.
```

---

## 4. Software Compilation & Flashing Instructions

### Prerequisites
- **Ubuntu 22.04 LTS** (or Raspberry Pi OS 64-bit)
- **ROS 2 Humble Hawksbill**
- **Python 3.10+** with `opencv-python`, `numpy`, `pyyaml`
- **PlatformIO / Arduino IDE** (for ESP32 MCU firmware)

### Building the ROS 2 High-Level Stack

```bash
# 1. Clone repository to workspace
cd ~/ros2_ws/src
git clone https://github.com/azmainofficial/Durnibar_WRO2026.git

# 2. Install dependencies
cd ~/ros2_ws
rosdep update
rosdep install --from-paths src --ignore-src -r -y

# 3. Build ROS 2 workspace
colcon build --symlink-install --packages-select durnibar_vision durnibar_nav durnibar_fsm

# 4. Source setup file
source install/setup.bash
```

### Flashing Microcontroller Firmware (ESP32)

```bash
# Navigate to firmware directory
cd src/firmware

# Compile and flash via PlatformIO
pio run --target upload --upload-port /dev/ttyUSB0
```

---

## 5. Execution Procedure (Starting Round - Rules 9.10 & 9.11)

1. Place the vehicle completely inside the starting zone switched OFF (Rule 9.6).
2. Flip the single **Main Power Switch** to turn on vehicle electronics (Rule 9.10).
3. The vehicle enters `BOOT_WAIT` state, awaiting the start button.
4. On judge's "GO!" signal, press the single **Start Push Button** (Rule 9.11).
5. The robot begins autonomous execution immediately.

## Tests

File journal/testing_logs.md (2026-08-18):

# Engineering Journal — Testing Logs & Metrics

> **WRO 2026 Future Engineers**  
> **Team Durnibar | Bangladesh**

---

## 1. Practice Run Performance Metrics

### Open Challenge Lap Testing (3-Lap Endurance Runs)

| Run ID | Corridor Width | Target Speed | Laps Completed | Total Time (s) | Avg Lap Time (s) | Result / Observations |
| :---: | :---: | :---: | :---: | :---: | :---: | :--- |
| **Run-01** | $1000\text{ mm}$ (Wide) | $1.5\text{ m/s}$ | 3 | $32.4\text{ s}$ | $10.8\text{ s}$ | Fast run; slight oscillation in corner 3 due to high $K_p$. |
| **Run-02** | $600\text{ mm}$ (Narrow) | $1.2\text{ m/s}$ | 3 | $38.1\text{ s}$ | $12.7\text{ s}$ | Smooth execution; narrow corridor maintained with $\pm 4\text{ cm}$ clearance. |
| **Run-03** | Mixed ($600/1000\text{ mm}$) | $1.2\text{ m/s}$ | 3 | $36.5\text{ s}$ | $12.17\text{ s}$ | Flawless turn transitions and autonomous finish section stop. |

---

## 2. Obstacle Avoidance & Parallel Parking Metrics

| Test Session | Traffic Signs Placed | Steering PID Setup | Pillar Avoidance % | Parking Alignment ($\Delta d$) | Parking Success Rate |
| :---: | :---: | :---: | :---: | :---: | :---: |
| **Session A** | 4 (2 Red, 2 Green) | $K_p=1.8, K_d=0.2$ | $80\%$ (1 bump) | $3.5\text{ cm}$ (Non-parallel) | $50\%$ |
| **Session B** | 6 (3 Red, 3 Green) | $K_p=1.4, K_d=0.4$ | $95\%$ | $1.8\text{ cm}$ (Parallel) | $85\%$ |
| **Session C** | 6 (3 Red, 3 Green) | $K_p=1.25, K_d=0.45$| **$100\%$** | **$0.8\text{ cm}$ (Parallel)** | **$95\%$** |

---

## 3. Computer Vision HSV Calibration Log

| Venue Lighting Condition | Ambient Lux | Red HSV Range | Green HSV Range | Detection Accuracy |
| :--- | :---: | :--- | :--- | :---: |
| **Lab Bench (Fluorescent)** | 450 Lux | `[0,120,70] - [10,255,255]` | `[35,80,70] - [85,255,255]` | $99.2\%$ |
| **Dim Indoor Room** | 180 Lux | `[0,90,50] - [10,255,255]` | `[30,60,50] - [85,255,255]` | $97.8\%$ |
| **Bright Competition Hall** | 850 Lux | `[0,140,80] - [10,255,255]` | `[38,90,80] - [85,255,255]` | $99.5\%$ |

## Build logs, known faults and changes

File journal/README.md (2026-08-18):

# Team Durnibar — Engineering Journal

> **WRO 2026 Future Engineers Category**  
> **Team Durnibar | Bangladesh**

---

## 📖 Journal Overview

The **Engineering Journal** records the development trajectory, testing milestones, design iterations, and field performance metrics of **Team Durnibar** throughout the **WRO 2026** season.

---

## 📂 Journal Index

1. **[testing_logs.md](./testing_logs.md)**: Detailed records of practice runs, lap timings, PID tuning experiments, computer vision lighting tests, and parallel parking success metrics.
2. **Commit History & Milestone Logs**: Documentation of key development milestones aligned with WRO GitHub submission deadlines.

---

## 🎯 Key Milestone Progress

- **Milestone 1 (2 Months Before Competition)**: Complete basic chassis assembly, motor drive, and initial baseline code commit ($>1/5$ codebase).
- **Milestone 2 (1 Month Before Competition)**: Sensor fusion integration (ToF + IMU), color segmentation pipeline, closed-loop PID lane following.
- **Milestone 3 (2 Weeks Before Competition)**: Final code freeze, parallel parking verification, engineering journal documentation complete.

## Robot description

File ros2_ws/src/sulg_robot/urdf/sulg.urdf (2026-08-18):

<?xml version="1.0"?>
<robot name="sulg_robot">

  <!-- Base Footprint (Ground Projection) -->
  <link name="base_footprint"/>

  <joint name="base_joint" type="fixed">
    <parent link="base_footprint"/>
    <child link="base_link"/>
    <origin xyz="0 0 0.033" rpy="0 0 0"/>
  </joint>

  <!-- Chassis Body (Base Link centered at rear axle) -->
  <link name="base_link">
    <visual>
      <origin xyz="0.10 0 0.04" rpy="0 0 0"/>
      <geometry>
        <box size="0.28 0.16 0.08"/>
      </geometry>
      <material name="dark_grey">
        <color rgba="0.15 0.15 0.18 1.0"/>
      </material>
    </visual>
    <collision>
      <origin xyz="0.10 0 0.04" rpy="0 0 0"/>
      <geometry>
        <box size="0.28 0.16 0.08"/>
      </geometry>
    </collision>
    <inertial>
      <mass value="1.5"/>
      <origin xyz="0.10 0 0.04" rpy="0 0 0"/>
      <inertia ixx="0.005" ixy="0.0" ixz="0.0" iyy="0.010" iyz="0.0" izz="0.012"/>
    </inertial>
  </link>

  <!-- RPLiDAR C1 Scanner Link -->
  <link name="laser_frame">
    <visual>
      <origin xyz="0 0 0" rpy="0 0 0"/>
      <geometry>
        <cylinder radius="0.035" length="0.03"/>
      </geometry>
      <material name="cyan">
        <color rgba="0.05 0.65 0.95 1.0"/>
      </material>
    </visual>
  </link>

  <joint name="laser_joint" type="fixed">
    <parent link="base_link"/>
    <child link="laser_frame"/>
    <origin xyz="0.10 0 0.12" rpy="3.14159 0 0"/>
  </joint>

  <!-- Camera Link (Front Bumper) -->
  <link name="camera_link">
    <visual>
      <origin xyz="0 0 0" rpy="0 0 0"/>
      <geometry>
        <box size="0.02 0.08 0.02"/>
      </geometry>
      <material name="green">
        <color rgba="0.1 0.8 0.4 1.0"/>
      </material>
    </visual>
  </link>

  <joint name="camera_joint" type="fixed">
    <parent link="base_link"/>
    <child link="camera_link"/>
    <origin xyz="0.24 0 0.08" rpy="0 0 0"/>
  </joint>

  <!-- Rear Left Wheel (Drive) -->
  <link name="rear_left_wheel">
    <visual>
      <geometry>
        <cylinder radius="0.033" length="0.026"/>
      </geometry>
      <material name="black">
        <color rgba="0.05 0.05 0.05 1.0"/>
      </material>
    </visual>
  </link>
  <joint name="rear_left_wheel_joint" type="continuous">
    <parent link="base_link"/>
    <child link="rear_left_wheel"/>
    <origin xyz="0 0.09 0" rpy="-1.5708 0 0"/>
    <axis xyz="0 0 1"/>
  </joint>

  <!-- Rear Right Wheel (Drive) -->
  <link name="rear_right_wheel">
    <visual>
      <geometry>
        <cylinder radius="0.033" length="0.026"/>
      </geometry>
      <material name="black">
        <color rgba="0.05 0.05 0.05 1.0"/>
      </material>
    </visual>
  </link>
  <joint name="rear_right_wheel_joint" type="continuous">
    <parent link="base_link"/>
    <child link="rear_right_wheel"/>
    <origin xyz="0 -0.09 0" rpy="-1.5708 0 0"/>
    <axis xyz="0 0 1"/>
  </joint>

  <!-- Front Left Steering Knuckle & Wheel -->
  <link name="front_left_steer_link"/>
  <joint name="front_left_steer_joint" type="revolute">
    <parent link="base_link"/>
    <child link="front_left_steer_link"/>
    <origin xyz="0.20 0.09 0" rpy="0 0 0"/>
    <axis xyz="0 0 1"/>
    <limit lower="-0.5236" upper="0.5236" effort="5.0" velocity="2.0"/>
  </joint>

  <link name="front_left_wheel">
    <visual>
      <geometry>
        <cylinder radius="0.033" length="0.026"/>
      </geometry>
      <material name="black">
        <color rgba="0.05 0.05 0.05 1.0"/>
      </material>
    </visual>
  </link>
  <joint name="front_left_wheel_joint" type="continuous">
    <parent link="front_left_steer_link"/>
    <child link="front_left_wheel"/>
    <origin xyz="0 0 0" rpy="-1.5708 0 0"/>
    <axis xyz="0 0 1"/>
  </joint>

  <!-- Front Right Steering Knuckle & Wheel -->
  <link name="front_right_steer_link"/>
  <joint name="front_right_steer_joint" type="revolute">
    <parent link="base_link"/>
    <child link="front_right_steer_link"/>
    <origin xyz="0.20 -0.09 0" rpy="0 0 0"/>
    <axis xyz="0 0 1"/>
    <limit lower="-0.5236" upper="0.5236" effort="5.0" velocity="2.0"/>
  </joint>

  <link name="front_right_wheel">
    <visual>
      <geometry>
        <cylinder radius="0.033" length="0.026"/>
      </geometry>
      <material name="black">
        <color rgba="0.05 0.05 0.05 1.0"/>
      </material>
    </visual>
  </link>
  <joint name="front_right_wheel_joint" type="continuous">
    <parent link="front_right_steer_link"/>
    <child link="front_right_wheel"/>
    <origin xyz="0 0 0" rpy="-1.5708 0 0"/>
    <axis xyz="0 0 1"/>
  </joint>

</robot>

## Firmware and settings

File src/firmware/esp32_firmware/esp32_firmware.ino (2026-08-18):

// =============================================================
// Sulg.ino  –  Main sketch: global definitions + setup + loop.
//
// All feature code lives in separate header files:
//   config.h        – pin & address definitions
//   globals.h       – extern declarations for shared state
//   kalman.h        – Kalman filter class
//   calibration.h   – CalibrationData struct + EEPROM routines
//   imu.h           – MPU6050 + QMC5883L + sensor fusion
//   motor.h         – TB6612 motor driver
//   encoder.h       – PCNT quadrature encoder
//   peripherals.h   – LEDs, non-blocking buzzer, button callbacks
//   oled_display.h  – OLED status screen
//   serial_parser.h – Serial integer reader
//   hardware_test.h – Full board self-test
// =============================================================

// ── Library & feature includes ────────────────────────────
#include <ESP32Servo.h>
#include <Wire.h>
#include <EEPROM.h>
#include "SSD1306Ascii.h"
#include "SSD1306AsciiWire.h"

#include "config.h"
#include "kalman.h"          // must come before globals.h (defines Kalman class)
#include "globals.h"         // extern declarations – no storage here
#include "calibration.h"
#include "imu.h"
#include "motor.h"
#include "encoder.h"
#include "peripherals.h"
#include "oled_display.h"
#include "serial_parser.h"
#include "hardware_test.h"
#include "odometry.h"
#include "pi_comm.h"


// =============================================================
// GLOBAL DEFINITIONS
// (extern declarations are in globals.h; actual storage is here)
// =============================================================

// Hardware objects
Servo            myServo;
SSD1306AsciiWire oled;

// Kalman instances
Kalman kalmanRoll;
Kalman kalmanPitch;

// Calibration data (loaded from EEPROM in setup)
CalibrationData calData;

// Servo
int currentServoAngle = 110;

// IMU / heading
unsigned long lastTime   = 0;
float         kalRoll    = 0.0f;
float         kalPitch   = 0.0f;
float         magHeading = 0.0f;

// Odometry / Dead Reckoning variables
float odomX      = 0.0f;
float odomY      = 0.0f;
float odomDist   = 0.0f;
float odomSpeed  = 0.0f;
float imuYaw     = 0.0f;


// Motor & encoder
int              motorSpeed   = 0;
volatile int32_t encoderCount = 0;

// LED states
bool greenState  = false;
bool yellowState = false;
bool redState    = false;

// Button debounce
bool          lastButton1State    = HIGH;
bool          lastButton2State    = HIGH;
unsigned long lastButton1Debounce = 0;
unsigned long lastButton2Debounce = 0;
volatile bool btn1Triggered       = false;
volatile bool btn2Triggered       = false;

// Non-blocking buzzer
unsigned long buzzerOffTime = 0;

// Sensor health flag – set false if MPU6050 or magnetometer fails init.
// Prevents IMU-dependent code from running and crashing the loop.
bool sensorsOK = true;

// =============================================================
// SETUP
// =============================================================
void setup() {
  Serial.begin(115200);

  // ── Buttons & boot button ─────────────────────────────
  pinMode(BOOT_BUTTON_PIN, INPUT_PULLUP);
  pinMode(BUTTON1_PIN,     INPUT_PULLUP);
  pinMode(BUTTON2_PIN,     INPUT_PULLUP);

  // ── Buzzer & LEDs (first! so they always work) ────────
  pinMode(BUZZER_PIN,     OUTPUT); digitalWrite(BUZZER_PIN,     LOW);
  pinMode(LED_GREEN_PIN,  OUTPUT); digitalWrite(LED_GREEN_PIN,  LOW);
  pinMode(LED_YELLOW_PIN, OUTPUT); digitalWrite(LED_YELLOW_PIN, LOW);
  pinMode(LED_RED_PIN,    OUTPUT); digitalWrite(LED_RED_PIN,    LOW);

  // Quick sequential blink: proves all 3 LED pins are wired & working.
  digitalWrite(LED_GREEN_PIN,  HIGH); delay(120); digitalWrite(LED_GREEN_PIN,  LOW);
  digitalWrite(LED_YELLOW_PIN, HIGH); delay(120); digitalWrite(LED_YELLOW_PIN, LOW);
  digitalWrite(LED_RED_PIN,    HIGH); delay(120); digitalWrite(LED_RED_PIN,    LOW);

  // ── Servo (attach BEFORE initMotor so it wins the first
  //    available LEDC channel/timer; motor gets the next one) ────
  myServo.attach(SERVO_PIN, 500, 2400);
  myServo.write(currentServoAngle);
  Serial.println("Servo: attached");

  // ── Motor & encoder ───────────────────────────────────
  initMotor();
  initEncoder();

  // ── EEPROM & calibration ──────────────────────────────
  EEPROM.begin(EEPROM_SIZE);
  loadCalibration(calData);

  // ── I²C bus ───────────────────────────────────────────
  Wire.begin(21, 22);           // SDA=21, SCL=22
  Wire.setClock(400000L);       // 400 kHz fast-mode

  // ── OLED ──────────────────────────────────────────────
  #if defined(OLED_TYPE) && (OLED_TYPE == SH1106)
    oled.begin(&SH1106_128x64, OLED_ADDR);
  #else
    oled.begin(&Adafruit128x64, OLED_ADDR);
  #endif
  oled.setFont(System5x7);
  oled.clear();

  // ── Sensor init (NON-FATAL: errors do NOT halt – servo, LEDs and motor keep working) ─────
  if (!initMPU6050()) {
    sensorsOK = false;
    oled.println("MPU6050 ERROR!");
    Serial.println("MPU6050 ERROR! IMU disabled.");
  }
  if (!initMagnetometer()) {
    sensorsOK = false;
    oled.println("MAG ERROR!");
    Serial.println("MAG ERROR! Heading disabled.");
  }

  // ── Seed Kalman filter dt timer ───────────────────────
  lastTime = micros();

  // ── Initialize Odometry ───────────────────────────────
  initOdometry();
  imuYaw = 0.0f; // Zero-heading reference at startup: car's initial facing direction is 0 degrees

  // ── Initialize Pi Communication ───────────────────────
  initPiComm();




  // ── Print command help ────────────────────────────────
  Serial.println("\n--- SYSTEM READY ---");
  Serial.print("  Sensors: "); Serial.println(sensorsOK ? "OK" : "ERROR (IMU disabled)");
  Serial.println("Commands:");
  Serial.println("  G/Y/L      - toggle Green / Yellow / Red LED");
  Serial.println("  B          - beep buzzer");
  Serial.println("  T          - full hardware test");
  Serial.println("  A          - 90 degree left turn test (speed 55)");

  Serial.println("  M<speed>   - set motor speed (-255..255)");
  Serial.println("  E          - read encoder count");
  Serial.println("  X          - reset encoder");
  Serial.println("  <0-180>    - move servo to angle");
  Serial.println("  B1 button  - 90 deg Left turn (speed 55)");
  Serial.println("  B2 button  - 90 deg Right turn (speed 55)");
  Serial.println("  BOOT button- calibrate IMU & magnetometer");


}

// =============================================================
// MAIN LOOP
// =============================================================
void loop() {

  // ── BOOT button (Disabled automatic calibration to prevent unwanted random freezing) ────
  // Calibration should only be invoked explicitly via serial command if requested.

  // ── BUTTON 1 (active-LOW) ───────────────────────────────
  {
    static bool button1ConfirmedState = HIGH;
    bool b1 = digitalRead(BUTTON1_PIN);
    if (b1 != lastButton1State) {
      lastButton1Debounce = millis();
      lastButton1State = b1;
    }
    if ((millis() - lastButton1Debounce) > DEBOUNCE_DELAY) {
      if (b1 != button1ConfirmedState) {
        button1ConfirmedState = b1;
        if (button1ConfirmedState == LOW) {
          handleButton1();
        }
      }
    }
  }

  // ── BUTTON 2 (active-LOW) ───────────────────────────────
  {
    static bool button2ConfirmedState = HIGH;
    bool b2 = digitalRead(BUTTON2_PIN);
    if (b2 != lastButton2State) {
      lastButton2Debounce = millis();
      lastButton2State = b2;
    }
    if ((millis() - lastButton2Debounce) > DEBOUNCE_DELAY) {
      if (b2 != button2ConfirmedState) {
        button2ConfirmedState = b2;
        if (button2ConfirmedState == LOW) {
          handleButton2();
        }
      }
    }
  }




  // ── Refresh encoder for OLED ──────────────────────────
  encoderCount = getEncoderCount();

  // ── Non-blocking buzzer tick ──────────────────────────
  updateBuzzer();

  // ── IMU sensor fusion (only if sensors initialised OK) ───
  if (sensorsOK) updateIMU();

  // ── Update Odometry ──────────────────────────────────────
  updateOdometry();

  // ── Raspberry Pi Communication & Telemetry Stream ────────
  updatePiComm();



  // ── OLED refresh @ 10 Hz ─────────────────────────────────
  static unsigned long lastDisplayUpdate = 0;
  if (millis() - lastDisplayUpdate > 100) {
    updateOLED();
    lastDisplayUpdate = millis();
  }
}

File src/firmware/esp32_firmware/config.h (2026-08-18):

// =============================================================
// config.h  –  Hardware pin definitions & compile-time constants
// Edit this file to adapt the sketch to different PCB layouts.
// =============================================================
#pragma once

// ── Servo ──────────────────────────────────────────────────
#define SERVO_PIN         18

// ── Buzzer & LEDs ──────────────────────────────────────────
#define BUZZER_PIN        19
#define LED_GREEN_PIN     16
#define LED_YELLOW_PIN    17
#define LED_RED_PIN        5

// ── Buttons (active LOW, external or internal pull-up) ─────
#define BOOT_BUTTON_PIN    0   // built-in BOOT button → triggers IMU calibration
#define BUTTON1_PIN       13   // toggles Red LED
#define BUTTON2_PIN       12   // toggles Green LED

// ── Motor driver (TB6612FNG) ───────────────────────────────
#define MOTOR_STBY_PIN    23
#define MOTOR_PWMA_PIN    25
#define MOTOR_AIN1_PIN    26
#define MOTOR_AIN2_PIN    27

// ── Quadrature encoder ─────────────────────────────────────
// NOTE: GPIO 34 & 35 are input-only with NO internal pull-up.
// Fit external 10 kΩ pull-up resistors to 3.3 V on both pins.
#define ENC_A_PIN         34
#define ENC_B_PIN         35

// ── I²C peripheral addresses ──────────────────────────────
#define MPU6050_ADDR      0x68
#define QMC5883L_ADDR     0x0D
#define OLED_ADDR         0x3C

// ── EEPROM ────────────────────────────────────────────────
#define EEPROM_SIZE       128

// ── OLED panel type: SSD1306 (default) or SH1106 ─────────
#define OLED_TYPE         SSD1306

// ── Button debounce window (ms) ───────────────────────────
#define DEBOUNCE_DELAY    50UL

// ── IMU Sensor Calibration ────────────────────────────────
// Set INVERT_GYRO_Z to true if MPU6050 is mounted upside down
#define INVERT_GYRO_Z     false


// ── Physical Vehicle & Wheel Geometry ──────────────────────
#define WHEEL_DIAMETER_MM      53.4f
#define WHEEL_CIRCUMFERENCE_MM 167.76f
#define WHEELBASE_MM           200.0f  // Distance between front & rear axles (mm)
#define TRACK_WIDTH_MM         200.0f  // Distance between left & right wheels (mm)

// ── Motor Driver Calibration ───────────────────────────────
// Set INVERT_MOTOR_DIR to true if positive motor speed drives the vehicle backward
#define INVERT_MOTOR_DIR       true

// ── Spur Gear & Encoder Calibration ────────────────────────
// Set ENCODER_INVERT_DIR to true if 2 spur gears reverse the rotation direction
#define ENCODER_INVERT_DIR     true


// Gear ratio between encoder shaft and wheel axle (Teeth_wheel / Teeth_encoder)
// Or calibrated scale factor: 609.6 mm actual / 170 mm measured = ~3.58588
#define DRIVE_GEAR_RATIO       3.58588f

// Base encoder resolution per motor shaft revolution
#define ENCODER_CPR            360.0f  

// Effective CPR at wheel: ENCODER_CPR / DRIVE_GEAR_RATIO
#define EFFECTIVE_ENCODER_CPR  (ENCODER_CPR / DRIVE_GEAR_RATIO)

// ── Steering Calibration ───────────────────────────────────
#define STEER_SERVO_CENTER     110     // Servo angle (degrees) for driving straight
#define SERVO_LEFT_LIMIT       170     // Servo angle for Left turn (20cm forward, 20cm left)
#define SERVO_RIGHT_LIMIT      50      // Servo angle for Right turn (20cm forward, 20cm right)
#define STEER_MAX_ANGLE_DEG    45.0f   // Physical wheel steer angle (degrees)

// ── Turn Control & Momentum Compensation ────────────────────
// Early braking lead angle (degrees) to stop motor before target heading so vehicle momentum lands exactly on target
#define TURN_BRAKE_LEAD_DEG    8.5f

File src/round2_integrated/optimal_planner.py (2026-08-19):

#!/usr/bin/env python3
"""
optimal_planner.py – Ultra-Fast Vectorized Ackermann Optimal Path Planner & Trajectory Optimizer
Designed for high-speed, sub-3ms autonomous navigation on Raspberry Pi 5 without ROS2.
"""

import time
import math
import numpy as np

class FastAckermannTrajectoryOptimizer:
    def __init__(self,
                 wheelbase_m=0.20,
                 robot_width_m=0.22,
                 robot_length_m=0.28,
                 max_steer_deg=30.0,
                 center_steer_pwm=110,
                 num_candidates=21,
                 horizon_m=1.8,
                 num_steps=25):
        """
        :param wheelbase_m: Distance between front and rear axles (m)
        :param robot_width_m: Total vehicle width including wheels (m)
        :param robot_length_m: Total vehicle length (m)
        :param max_steer_deg: Maximum wheel steering deflection (+/- deg)
        :param center_steer_pwm: Servo PWM angle for driving straight
        :param num_candidates: Number of steering trajectory rollouts to evaluate
        :param horizon_m: Forward prediction horizon (m)
        :param num_steps: Number of discrete integration steps along each rollout
        """
        self.wheelbase = wheelbase_m
        self.robot_width = robot_width_m
        self.robot_half_width = robot_width_m / 2.0
        self.robot_length = robot_length_m
        self.max_steer_deg = max_steer_deg
        self.center_steer = center_steer_pwm
        self.num_candidates = num_candidates
        self.horizon_m = horizon_m
        self.num_steps = num_steps

        # Tunable cost weights
        self.weights = {
            "w_clearance": 6.0,       # Strict repulsion from walls and obstacles
            "w_progress": 2.0,        # Heading towards the furthest open corridor
            "w_wro_rules": 8.0,       # Strict rule enforcement (Green=Left, Red=Right)
            "w_smooth": 0.8,          # Steering rate penalty to prevent wobble
            "w_centering": 2.5,       # Track centerline bias
            "safety_margin_m": 0.22,  # Desired clearance buffer around robot
            "max_lat_accel": 2.2      # Maximum lateral cornering acceleration (m/s^2)
        }

        # Candidate steering angles (-max_steer_deg to +max_steer_deg)
        self.steer_angles_deg = np.linspace(-self.max_steer_deg, self.max_steer_deg, self.num_candidates)
        self.steer_angles_rad = np.radians(self.steer_angles_deg)

        # Precompute normalized kinematic rollouts for unit speed
        self._precompute_trajectory_templates()

        # State tracking
        self.last_selected_steer_deg = 0.0
        self.last_plan_time = time.perf_counter()
        self.last_latency_ms = 0.0
        self.last_error = 0.0

    def _precompute_trajectory_templates(self):
        """
        Precompute normalized 2D trajectory coordinate rollouts for all candidate steering angles.
        Shape: (num_candidates, num_steps, 2) where [:, :, 0] is X (forward), [:, :, 1] is Y (left)
        """
        dt = 0.05
        v = 1.0  # Unit speed template
        step_dist = self.horizon_m / float(self.num_steps)
        dt_eff = step_dist / v

        self.template_trajectories = np.zeros((self.num_candidates, self.num_steps, 2), dtype=np.float32)
        self.template_headings = np.zeros((self.num_candidates, self.num_steps), dtype=np.float32)

        for i, delta in enumerate(self.steer_angles_rad):
            x, y, theta = 0.0, 0.0, 0.0
            for s in range(self.num_steps):
                x += v * math.cos(theta) * dt_eff
                y += v * math.sin(theta) * dt_eff
                theta += (v / self.wheelbase) * math.tan(delta) * dt_eff
                self.template_trajectories[i, s, 0] = x
                self.template_trajectories[i, s, 1] = y
                self.template_headings[i, s] = theta

        # Precompute pre-rounded Python lists for instant telemetry serialization (<0.05ms)
        self.template_trajectories_list = [
            [[round(float(p[0]), 3), round(float(p[1]), 3)] for p in self.template_trajectories[i]]
            for i in range(self.num_candidates)
        ]

    def update_config(self, cfg_dict):
        """Live update tunable planner weights from web dashboard or config file."""
        for k in self.weights:
            if k in cfg_dict:
                try:
                    self.weights[k] = float(cfg_dict[k])
                except (ValueError, TypeError):
                    pass

    def plan_optimal_trajectory(self,
                                lidar_points,
                                towers=None,
                                current_speed_pwm=110,
                                base_speed_pwm=110,
                                left_wall_m=0.8,
                                right_wall_m=0.8,
                                preferred_angle_deg=0.0,
                                challenge_mode="OPEN_CHALLENGE"):
        """
        Computes the collision-free, curvature-optimal trajectory in < 3 ms.

        :param lidar_points: List of (angle_deg, dist_mm) from 360-degree LiDAR
        :param towers: List of detected fused towers [{'x_m', 'y_m', 'dist_m', 'angle_deg', 'color'}, ...]
        :param current_speed_pwm: Current motor speed PWM
        :param base_speed_pwm: Target nominal speed PWM
        :param left_wall_m: Smoothed left wall distance (m)
        :param right_wall_m: Smoothed right wall distance (m)
        :param preferred_angle_deg: Fallback guidance angle from gap finder
        :param challenge_mode: "OPEN_CHALLENGE", "OBSTACLE_CHALLENGE", "PARKING", "IDLE"
        :return: dict with {
            'steer_pwm': int (50..170),
            'steer_deg': float,
            'target_speed_pwm': int,
            'optimal_path': list of [x, y],
            'candidate_paths': list of dict,
            'latency_ms': float,
            'cost': float,
            'safe': bool
        }
        """
        t_start = time.perf_counter()
        if towers is None:
            towers = []
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

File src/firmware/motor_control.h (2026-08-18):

/**
 * @file motor_control.h
 * @brief TB6612FNG Motor Driver & Ackermann Servo Steering Controller
 */

#ifndef MOTOR_CONTROL_H
#define MOTOR_CONTROL_H

#include "config.h"
#include <ESP32Servo.h>

static Servo g_steeringServo;

/**
 * @brief Initialize motor driver GPIOs and attach steering servo
 */
inline void initMotorAndServo() {
    pinMode(PIN_MOTOR_PWMA, OUTPUT);
    pinMode(PIN_MOTOR_AIN1, OUTPUT);
    pinMode(PIN_MOTOR_AIN2, OUTPUT);
    pinMode(PIN_MOTOR_STBY, OUTPUT);

    // Drive STBY HIGH to enable TB6612FNG H-Bridge
    digitalWrite(PIN_MOTOR_STBY, HIGH);

    // Servo Setup
    ESP32PWM::allocateTimer(0);
    g_steeringServo.setPeriodHertz(50);
    g_steeringServo.attach(PIN_SERVO, 1000, 2000);
    g_steeringServo.write(SERVO_CENTER);
}

/**
 * @brief Set Rear Drive Motor Speed (-255 to 255)
 * @param speed Speed value: positive for forward, negative for reverse, 0 for stop
 */
inline void setMotorSpeed(int speed) {
    digitalWrite(PIN_MOTOR_STBY, HIGH);

    if (speed > 0) { // Forward
        digitalWrite(PIN_MOTOR_AIN1, HIGH);
        digitalWrite(PIN_MOTOR_AIN2, LOW);
        analogWrite(PIN_MOTOR_PWMA, constrain(speed, 0, 255));
    } else if (speed < 0) { // Reverse
        digitalWrite(PIN_MOTOR_AIN1, LOW);
        digitalWrite(PIN_MOTOR_AIN2, HIGH);
        analogWrite(PIN_MOTOR_PWMA, constrain(-speed, 0, 255));
    } else { // Active Brake
        digitalWrite(PIN_MOTOR_AIN1, LOW);
        digitalWrite(PIN_MOTOR_AIN2, LOW);
        analogWrite(PIN_MOTOR_PWMA, 0);
    }
}

/**
 * @brief Set Steering Angle with Ackermann Protection
 * @param angle Target steering angle in degrees
 */
inline void setSteeringAngle(int angle) {
    int clampedAngle = constrain(angle, SERVO_MIN_ANGLE, SERVO_MAX_ANGLE);
    g_steeringServo.write(clampedAngle);
}

/**
 * @brief Emergency stop vehicle (Neutral steering + motor brake)
 */
inline void stopVehicle() {
    setMotorSpeed(0);
    setSteeringAngle(SERVO_CENTER);
}

#endif // MOTOR_CONTROL_H

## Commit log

2026-06-09 Add installation guide for ROS2 Jazzy on Raspberry Pi 5
    This README guide details the installation process for ROS2 Jazzy on a Raspberry Pi 5 running Ubuntu Server 24.04, including setup, troubleshooting, and optional fan control.
2026-08-09 docs: restructure repository for WRO 2026 Future Engineers guidelines & Appendix C documentation
    [Durnibar 2.0.f3z, Gear Box v2.0.f3d]
2026-08-09 docs: update hardware specs to Raspberry Pi 5 (8GB), Fifine K420 Webcam (108° FOV), and ESP32
2026-08-09 feat(firmware): add low-level ESP32 firmware for PWM motor/servo control, ToF sensors, BNO055 IMU, and RPi 5 serial bridge
2026-08-09 docs(firmware): update ESP32 pin diagram with TB6612FNG, wheel encoders, status LEDs, MPU6050, QMC5883L, and SSD1306 OLED
2026-08-09 feat(firmware): add native Arduino IDE sketch esp32_firmware.ino and setup guide
2026-08-09 refactor(firmware): modularize ESP32 code into function-based header files (config.h, motor_control.h, encoder.h, kalman_filter.h, sensors_display.h)
2026-08-09 feat(ros2): add ROS 2 Humble nodes for Slamtec RPLIDAR C1 360° LaserScan navigation, Fifine K420 vision, and high-level FSM
2026-08-09 Polish Criterion 1 docs, add battery runtimes & ESP32 pin mappings
2026-08-09 Add generated circuit schematic PNG and embed it in schematics README
2026-08-09 Update circuit schematic with the official ESP32 wiring diagram
2026-08-09 Add VS Code 3D/CAD extensions recommendations and view instructions in README
2026-08-18 Initial commit: Sulg WRO autonomous navigation workspace update with 15cm final forward move
    [sulg.urdf, sulg.urdf.xacro]
2026-08-18 Format repository layout: remove duplicate code from root, organize ESP32 Arduino project into src/firmware/esp32_firmware/esp32_firmware.ino
2026-08-18 Implement hybrid discrete 90-degree cornering state machine in odometry challenge
2026-08-18 Correct corner detection to only trigger on physical front wall, add lap-complete buzzer beep, and create parking_out directory
    [wro_pi_system.py]
2026-08-18 Fix center_pwm scoping bug in esp32_loop
    [wro_pi_system.py]
2026-08-19 Add save block sequence options and dynamic parking out with LiDAR auto-detect exit routing
2026-08-19 Implement Auto-LiDAR exit steering option inside the Block Sequence Editor
2026-08-19 Simplify Auto-LiDAR labeling inside dropdown menus and forms
2026-08-19 Implement Auto-LiDAR (In) and Auto-LiDAR (Out) steering selections inside block editor
2026-08-19 Change Auto-LiDAR blocks to use static cached parameters scanned at startup to prevent mid-run movement drift
    [wro_pi_system.py]
2026-08-19 Add Magenta (Pink) color calibration tab controls and preview mask filters
2026-08-19 Implement smooth Proportional Wall Centering and Config-guided Corner turn locking to prevent center wall collisions
    [wro_pi_system.py]
2026-08-19 Reset state to DRIVE_STRAIGHT upon stuck recovery completion to prevent immediate re-locking into corner-hitting steer angles
    [deploy_to_pi.py, wro_pi_system.py]
2026-08-19 Configure round1_open_challenge folder with 15cm final forward run, auto start, and deploy IP to 192.168.137.164
2026-08-19 Fix inverted Red/Green evasion rules and HUD labels so Green passes LEFT and Red passes RIGHT
    [wro_pi_system.py]
2026-08-19 Enhance LiDAR-Camera tower fusion with 40-deg search window and camera virtual tower fallback to guarantee 100% color rule enforcement
2026-08-19 Implement geometric shape filtering (Aspect Ratio <= 1.25, Max Width <= 250px, Solidity Extent >= 0.40) to eliminate floor line false positives
2026-08-19 Save calibrated HSV color values from Pi and set headless competition mode
2026-08-19 Implement Virtual Target Corridor Path & PID Controller for Green (left corridor) and Red (right corridor) blocks
2026-08-19 Strengthen pillar clearance buffer to 0.35m and increase wrong side rule penalty to 500.0 with hard 0.32m safety buffer
    [deploy_to_pi.py, optimal_planner.py, wro_pi_system.py]
